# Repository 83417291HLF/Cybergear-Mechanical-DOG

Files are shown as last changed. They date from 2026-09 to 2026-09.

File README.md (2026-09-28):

# Cybergear Mechanical DOG · 8 自由度并联四足机器人

面向 **2026 ROBOCON 竞赛备赛**的四足机器人项目，采用 **RoboMaster A 板、8 个小米 CyberGear 电机和双 CAN 总线**。每条腿由两个电机驱动，软件基于 STM32 HAL，通过 SBUS 遥控生成足端轨迹，并结合板载 IMU 做俯仰、横滚高度补偿。

本文以当前源码和 Keil 工程配置为准。参赛用途由项目作者提供，不表示已经完成赛事规则符合性验证或性能验收。

[代码逐层拆解与问题清单](docs/CODE_WALKTHROUGH.md) · [编译与上机检查](docs/BUILD_AND_BRINGUP.md) · [English](README.en.md)

## 当前实现

| 功能 | 当前代码状态 |
| --- | --- |
| 8 电机控制 | CAN1：ID 1–4；CAN2：ID 5–8，运控模式 |
| 遥控输入 | USART1 + DMA + IDLE，解析 10 个 SBUS 通道 |
| 行走 | 前后步幅、左右差动转向、原地踏步 |
| 步态 | 对角腿相差半周期，摆动相使用摆线轨迹，支撑相匀速回摆 |
| 姿态补偿 | MPU6500 + IST8310 → 四元数姿态解算 → 腿高补偿 |
| 关节控制 | 几何 IK、位置限幅、关节弹簧阻尼力矩补偿、电机内部 PD |
| VMC / 跳跃 | 存在实验文件，但未接入当前 Keil 编译目标和主循环 |
| 调度 | 裸机轮询，目标周期 10 ms；当前主程序未启动 FreeRTOS |

**当前版本属于开发代码快照。** 静态检查发现 SBUS DMA 缓冲区长度不一致、失联分支可继续读取旧指令、反馈角度与控制角度单位不一致等问题，详见[代码拆解](docs/CODE_WALKTHROUGH.md)。归档不代表固件已经通过编译或实机验证。

## 软件结构

```text
software/sizujixgou1123/
├── Core/                   STM32 初始化、主循环、中断入口
├── Drivers/                STM32F4 HAL、CMSIS 与芯片头文件
├── MDK-ARM/
│   ├── sizujixgou1123.uvprojx  Keil 工程入口
│   ├── CyberGear/          电机协议、反馈解析、CAN BSP
│   ├── SBUS/               遥控接收与解析
│   ├── leg/                当前步态、IK；另含实验性 VMC 等文件
│   ├── MPU6500/            IMU 读取、四元数姿态解算
│   ├── IST8310/            磁力计驱动、标量卡尔曼滤波
│   └── RTE/               配置及未接入的跳跃实验代码
└── sizujixgou1123.ioc      STM32CubeMX 配置
三维模型/                   机械设计资料
CyberGear微电机/            电机说明书、模型、固件等参考资料
docs/                       代码分析、编译与上机说明
```

```mermaid
flowchart TD
    RC[SBUS 遥控器] --> UART[USART1 DMA / IDLE 回调]
    UART --> Remote[remoter 通道状态]
    Remote --> Control[update_control_from_remote]
    IMU[MPU6500 + IST8310] --> Attitude[mpu_get_data / IMUupdate1]
    Attitude --> Gait[update_quadruped_gait]
    Control --> Gait
    Gait --> IK[leg_set_position_idx：IK + 关节补偿]
    IK --> Motor[motor_controlmode]
    Motor --> CAN[CAN1 / CAN2]
    CAN --> Eight[8 个 CyberGear 电机]
    Eight --> Feedback[CAN 接收中断：角度 / 速度 / 力矩 / 温度]
    Feedback --> IK
```

## 硬件与电机映射

| 项目 | 当前源码配置 |
| --- | --- |
| 主控 | RoboMaster A 板，STM32F427IIHx |
| 时钟 | 外部时钟 12 MHz，SYSCLK 168 MHz，APB1 42 MHz |
| CAN1 | PD0 RX / PD1 TX；1 Mbit/s |
| CAN2 | PB12 RX / PB13 TX；1 Mbit/s |
| 遥控串口 | USART1，PB7 RX / PB6 TX，100000 baud，8 数据位 + 偶校验 + 2 停止位（HAL 配置为 9B 含校验） |
| 调试串口 | UART7，PE7 RX / PE8 TX，115200 baud，8N1 |
| 惯性传感器 | SPI5 连接 MPU6500，驱动同时读取 IST8310 |

CAN 位率由 `42 MHz / [3 × (1 + 9 + 4)] = 1 MHz` 推导。实际接线还应核对 A 板接口标识及收发器连接。

| 腿编号 | 源码约定位置 | 电机 ID | 总线 | 步态相位 |
| --- | --- | --- | --- | --- |
| 0 | 左前 LF | 1、2 | CAN1 | 0 |
| 1 | 左后 LH | 3、4 | CAN1 | 0.5 |
| 2 | 右后 RH | 5、6 | CAN2 | 0 |
| 3 | 右前 RF | 7、8 | CAN2 | 0.5 |

位置由姿态补偿分组与 VMC 头文件交叉核对，装配后仍须逐电机确认。右侧腿发送的位置和力矩取反；实际代码中 **0/2 同相，1/3 同相**，部分旧注释与此不一致。

## 遥控映射

以下 CH 编号从 1 开始，`ch[]` 下标从 0 开始。解析以原始值 992 为中心。

| 通道 | 数组下标 | 功能 |
| --- | --- | --- |
| CH1 | `ch[0]` | 转向步幅；死区 40，最终限幅 ±60 mm |
| CH3 | `ch[2]` | 前后步幅；死区 40，取反映射，限幅 ±90 mm |
| CH5 | `ch[4]` | 非零时允许前后/转向指令，零时清零两者 |
| CH6 | `ch[5]` | 大于 500 时原地踏步；当前独立于 CH5 |
| CH7 | `ch[6]` | 大于 500：抬腿 130 mm、周期 0.3 s；否则 60 mm、0.2 s |
| CH8 | `ch[7]` | 大于 500：190 mm；小于 −500：270 mm；中间：213.2 mm 基准高度 |

CH5 当前不是整机急停，关闭后仍发送站立命令，CH6 可以继续触发踏步。遥控器开关的实际输出须先通过通道监测确认。`side_s` 字段未进入当前轨迹计算，不能据此宣称支持横移。

## 编译入口与关键参数

打开 [Keil 工程](software/sizujixgou1123/MDK-ARM/sizujixgou1123.uvprojx)。工程记录的工具链为 ARMCC 5.05 update 1，器件包为 `Keil.STM32F4xx_DFP.2.17.0`。完整步骤见[编译与上机检查](docs/BUILD_AND_BRINGUP.md)。

| 参数 | 源码当前值 | 位置 |
| --- | --- | --- |
| 几何尺寸 | L1 = 100 mm，L2 = 200 mm，足端延长 = 45 mm | `leg/leg.h` |
| 角度偏置 | π/2 | `leg/leg.h` |
| 默认高度 / 抬腿高度 / 周期 | 213.2 mm / 60 mm / 0.2 s | `leg/leg.c` |
| 姿态补偿增益 | pitch、roll 均为 2 mm/° | `leg/leg.c` |
| 补偿限幅 / 变化率 | 每腿合成补偿 ±100 mm / 每轴 20 mm/s | `leg/leg.c` |
| 关节目标限幅 | 镜像前 −1.2～1.4 rad | `leg/leg.c` |
| 运控 PD | Kp = 13，Kd = 0.9 | `leg/leg.c` |

这些数值是源码参数，不是整机性能指标或本次测试的推荐参数。

## 后续开发重点

1. 修复接收越界、失联处理与反馈单位，建立明确的停机状态。
2. 统一左右腿坐标、关节方向和零位标定，修正 IK 可达域处理。
3. 测量控制周期，减少 CAN 重复发送与阻塞延时。
4. 修正姿态滤波状态共享，补充传感器有效性判断。
5. 在单腿测试通过后，验证完整并联机构的 FK / Jacobian 和 VMC。

## 仓库说明

源码、CubeMX/Keil 配置与机械资料用于协作维护。生成目标文件、历史构建产物、IDE 用户状态、重复的 `software.zip` 和第三方上位机运行包不纳入版本控制，本地文件保留。源码混有不同中文编码，本次文档整理不批量转码控制代码。

当前未为作者自有代码新增开源许可证；第三方 HAL、CMSIS 及电机驱动保留原有许可文件与作者声明。公开仓库不自动授予任意再分发许可。

远端原有的历史归档 `sizujixgou1123 (3).zip` 保留；阅读和后续开发以展开后的 `software/` 为准。

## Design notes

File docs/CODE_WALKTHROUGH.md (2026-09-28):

# 从代码拆解 Cybergear Mechanical DOG

分析对象为 `software/sizujixgou1123`。相对路径以下均以该目录为起点。分析依据为源码、函数调用和 `.uvprojx` 源文件清单，不以旧编译产物推断当前功能。

## 1. 入口与执行时序

[`Core/Src/main.c`](../software/sizujixgou1123/Core/Src/main.c) 的执行顺序：

```text
HAL_Init → SystemClock_Config
→ GPIO / DMA / CAN1 / CAN2 / USART1 / UART7 / TIM6 / TIM7 / SPI5 初始化
→ can_bsp_init
→ USART1 ReceiveToIdle DMA → 启动 TIM6 中断
→ mpu_device_init → quadruped_init
→ while (1)
    每当 HAL_GetTick 差值 ≥ 10 ms：
        mpu_get_data
        update_control_from_remote
        update_quadruped_gait(0.01)
    每 500 ms 翻转 LED
```

当前调度是裸机轮询。TIM2 回调负责 `HAL_IncTick()`；TIM6 虽然启动，但 `HAL_TIM_PeriodElapsedCallback()` 未实现 TIM6 的控制任务。旧输出目录中的 `freertos.o`、`tasks.o` 不代表当前主程序在运行 RTOS。

这里的 100 Hz 是目标频率：`last_tick = now`，传入的 `dt` 固定为 0.01。发送电机命令的阻塞延时和传感器读取可能造成超期，超期后没有追赶执行或真实时间步长修正。

## 2. 遥控输入层

[`MDK-ARM/SBUS/sbus.c`](../software/sizujixgou1123/MDK-ARM/SBUS/sbus.c) 在 USART1 的 IDLE/DMA 回调中解析 SBUS 数据：检查首字节 `0x0F`、尾字节 `0x00`，从 11-bit 打包数据提取 10 通道，统一减去 992。

[`update_control_from_remote()`](../software/sizujixgou1123/MDK-ARM/leg/leg.c) 将通道转换为步态参数：前后步幅 `S`、转向步幅 `yaw_s`、踏步标志、抬腿高度 `H`、周期 `T_cycle` 和基准腿高。步幅采用 `0.8 × 旧值 + 0.2 × 目标值` 平滑；它们是毫米尺度的轨迹幅度，不是 m/s 的速度命令。

CH5 仅控制前后/转向，CH6 独立触发原地踏步。`side_s` 虽然声明在 `GaitConfig`，当前没有进入轨迹生成。

## 3. 足端轨迹和机身姿态补偿

主要逻辑集中在 [`MDK-ARM/leg/leg.c`](../software/sizujixgou1123/MDK-ARM/leg/leg.c)。

每条腿的步幅：左侧 `S + yaw_s`，右侧 `S - yaw_s`。相位表达式为：

```c
phase = timer / T_cycle + ((i == 1 || i == 3) ? 0.5f : 0.0f);
```

因此是 0/2 同相、1/3 同相，配合 LF/LH/RH/RF 腿序形成对角配对。旧注释所写的“0、3 同相”与表达式不同。

摆动相占半周期，归一化时间为 `s`，`sigma = 2πs`：

```text
x = -步幅/2 + 步幅 × (sigma - sin(sigma)) / (2π)
y = y_base - H × (1 - cos(sigma)) / 2
```

支撑相令 x 从正半步幅线性回到负半步幅，y 保持基准高度并叠加补偿。停止行走时 timer 清零，各腿 x = 0，但仍更新姿态补偿和电机位置。

姿态链路为 `mpu_get_data → IMUupdate1 → imu.pit0/rol0 → 腿高补偿`。每轴按 2 mm/° 放大，经过系数 0.4 的低通及 20 mm/s 变化率限制，再按前后、左右腿加减；每腿合成补偿限制为 ±100 mm。行走时只在支撑相补偿，静止时四腿均补偿。

`y_base += (target_y_base - y_base) * 1.0f` 实际一步到达目标，不具备注释暗示的渐变效果。IMU 反馈单位是度，几何 IK 和电机目标使用弧度，二者不可混用。

## 4. 单腿 IK 与关节补偿

[`leg_set_position_idx()`](../software/sizujixgou1123/MDK-ARM/leg/leg.c) 使用 `L1 = 100`、`L2_EFF = 200 + 45 = 245` mm 和 π/2 偏置。

先做左右镜像，再以足端距离 L、方向角 psi 和余弦定理求 phi：

```text
L² = cx² + cy²
psi = asin(-cx/L)
phi = acos((L² + L1² - L2_EFF²)/(2 L1 L))
pos1 = -(phi - psi) + π/2
pos2 = -(phi + psi) + π/2
```

这描述源码采用的几何模型；完整并联连杆闭环、装配分支和实际零位仍须与机械图纸及单腿测量对照。

附加力矩公式是 `tau = stiffness × (目标角 - 反馈角) - 0.1 × 反馈速度`。刚度为 `2 × clamp(213.2/y, 0.8, 1.5)`，力矩限幅 ±12，位置在镜像前限幅 −1.2～1.4 rad，最终传入 `motor_controlmode(..., 13, 0.9)`。右侧位置和力矩发送前取负。

因此当前是**位置轨迹 + 关节空间弹簧阻尼补偿 + 电机内部 PD**。足端力通过 `JᵀF` 分配的实验性 VMC 没有进入这条运行链路。

## 5. CAN 与电机协议层

[`CyberGear/bsp_CAN.c`](../software/sizujixgou1123/MDK-ARM/CyberGear/bsp_CAN.c) 启动两条总线，用过滤器组 0、14 接收 FIFO0 中断，当前掩码放行全部 ID。

[`CyberGear/cybergear.c`](../software/sizujixgou1123/MDK-ARM/CyberGear/cybergear.c) 封装使能、停止、设零位、参数写入、运控和反馈解码。运控帧将位置、速度、Kp、Kd 各编码为 16 位并填入 8 字节载荷，力矩编码进入扩展 ID。主机 ID 定义为 `0xFD`。

`can_txd(hcan)` 是头文件宏，展开为 `HAL_CAN_AddTxMessage(hcan, &txMsg, tx_data, &send_mail_box)`，所以函数内的局部 `tx_data` 会实际传入 HAL，并非丢失载荷。当前真正的问题是 `motor_controlmode()` 在等待邮箱前后调用该宏两次，存在重复发送和首发失败未处理的问题。

接收回调根据总线及电机 ID 分发给 `mi_motor_can1/2[0..3]`，更新角度、速度、力矩、温度和错误位。数组实际声明容量为 5，每条总线只初始化 4 个元素。

## 6. 当前目标之外的文件

`.uvprojx` 中的主要业务源文件是 `leg.c`、`cybergear.c`、`bsp_CAN.c`、`sbus.c`、`mpu6500.c`、`process.c`、`mahony.c`、`ist8310.c`、`kalman.c`。加入工程不意味着所有函数均被调用：姿态实际入口是 `IMUupdate1()`。

| 文件 | 检查结果 |
| --- | --- |
| `leg/quadruped_vmc.c/.h` | 未加入当前编译目标；尝试足端弹簧力与 Jacobian 转置控制 |
| `leg/gait_planner.c` | 未加入目标；包含不存在的 `leg0_config.h`，依赖 `leg0` |
| `leg/robot_config.c` | 当前为空文件，不能视作集中参数管理已经实现 |
| `RTE/jump.c/.h` | 未加入当前编译目标 |
| `dm_IMU.c`、`dm_imu.h`、`SBUS/dm_imu.*`、`imu.c` | 当前工程未选用的其他 IMU 相关文件 |

VMC 实验代码的头文件写 12 kg，而 `.c` 内定义 10 kg；足端误差直接使用毫米，刚度注释为 N/m，尚未统一单位。其 Jacobian 表达式也需要按真实并联机构闭环重新推导，不能直接视作验证过的整机力控。

## 7. 已确认的问题与待验证项

以下为静态审查结果，本次归档未修改控制源码。优先级表示修复顺序，不表示实机已复现。

| 优先级 | 位置与证据 | 影响及处理方向 |
| --- | --- | --- |
| P0 | `sbus.h` 定义 `BUFF_SIZE=25`、`sbus.c` 分配 25 字节，但 main 与回调都启动 `BUFF_SIZE*2` 的 DMA | DMA 可写到缓冲区之外；统一容量与长度，在完整帧校验后解析 |
| P0 | `update_control_from_remote()` 的离线分支只清零步幅，没有 return；后续读取旧通道 | 旧通道可以重新恢复运动；离线必须终止控制输入处理并清理踏步状态 |
| P0 | `sbus_frame_parse()` 仅用 `buf[23] == 0x0C` 判离线，无接收超时 | 断线不再收帧时可一直保持在线；应按位检查故障标志并加入有效帧时间戳 |
| P1 | `Motor_Data_Handler()` 用 `MIN_P=-720/MAX_P=720` 解码 Angle，IK 目标直接以 rad 与它相减 | 反馈与控制数值尺度不一致；统一单位后重新验证补偿，不可只调增益 |
| P1 | `motor_controlmode()` 连续两处 `can_txd`，返回值未检查，末尾 `HAL_Delay(1)` | 命令重复、丢帧不可见、周期预算被占用；改为单次受控发送并统计失败 |
| P1 | SBUS 回调在解析前重启 DMA，且允许 `Size < 25` 时进入解析 | 读写竞争及残留数据可能被当作完整帧；增加帧长验证、快照/双缓冲和重同步 |
| P1 | `check_and_recover_motors()` 遍历 CAN1 的 0..7，数组容量仅 5，且遗漏 CAN2 | 潜在越界；当前主循环未调用，接入前必须修复为两总线各 4 个，不能自动无条件恢复 |
| P1 | 右侧发送目标取反，但误差计算直接使用未转换的右侧反馈 | 即便修正角度单位仍可能符号错误；定义统一关节坐标，反馈与目标采用同一转换 |
| P1 | IK 限制 L 后仍在余弦公式中使用原始 L_sq | 越界足端目标没有被一致投影到可达域；同时调整坐标/距离及平方项 |
| P1 | `KalmanFilter()` 用单份 static 状态，`IMUupdate1()` 对 pitch/roll/yaw 连续调用 | 三轴滤波互相污染；每轴使用独立状态 |
| P1 | `IMUupdate1()` 对加速度、磁场和四元数模长直接相除 | 零/无效测量可传播 NaN；增加有效性门限，首帧时间初始化及异常恢复 |
| P1 | `quadruped_init()` 上电即使能、设零位、发零角命令 | 任意上电姿态可能改变机械参考；拆分标定与运行状态 |
| P2 | 高度调整系数是 1，固定 dt，CAN 反馈无帧类型/DLC/时效完整检查 | 高度跃变、时序误差和无效反馈风险；增加速率限制、实际周期统计及反馈验证 |

推荐先修复内存与失联问题，再统一单位和坐标，随后验证时序及 IMU，最后开展 VMC。每一步都应保留单腿/整机测量记录。

## 8. 验证边界

本次属于代码阅读、工程清单核对与文档整理；没有用历史构建日志代替当前编译，没有宣称机器人已达到某个速度、负载、跳跃高度或竞赛成绩。编译与硬件测试步骤见[上机说明](BUILD_AND_BRINGUP.md)。

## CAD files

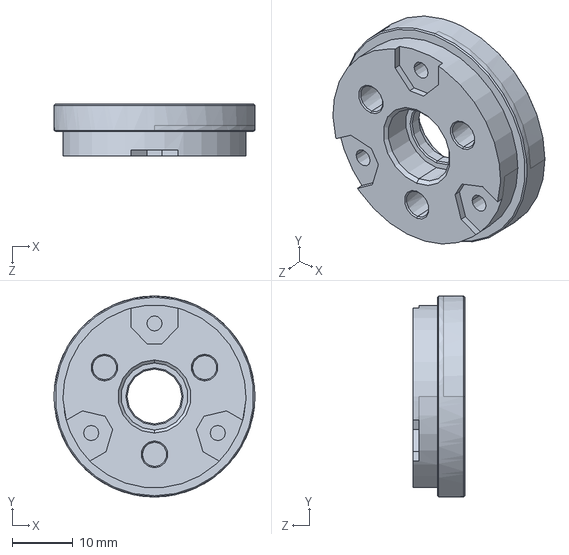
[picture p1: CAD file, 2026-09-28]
CyberGear微电机/电机三维图纸/1_1_02_EB671-500_1_1_1_1_1.SLDPRT
33.0 x 33.0 x 8.50 mm

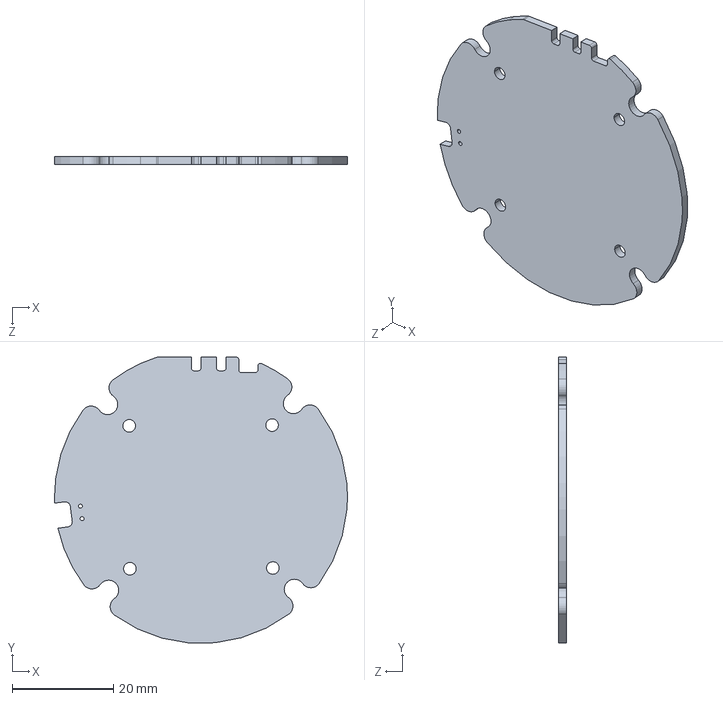
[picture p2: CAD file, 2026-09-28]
CyberGear微电机/电机三维图纸/0411-2_4_1_3_1.SLDPRT
58.0 x 56.6 x 1.61 mm

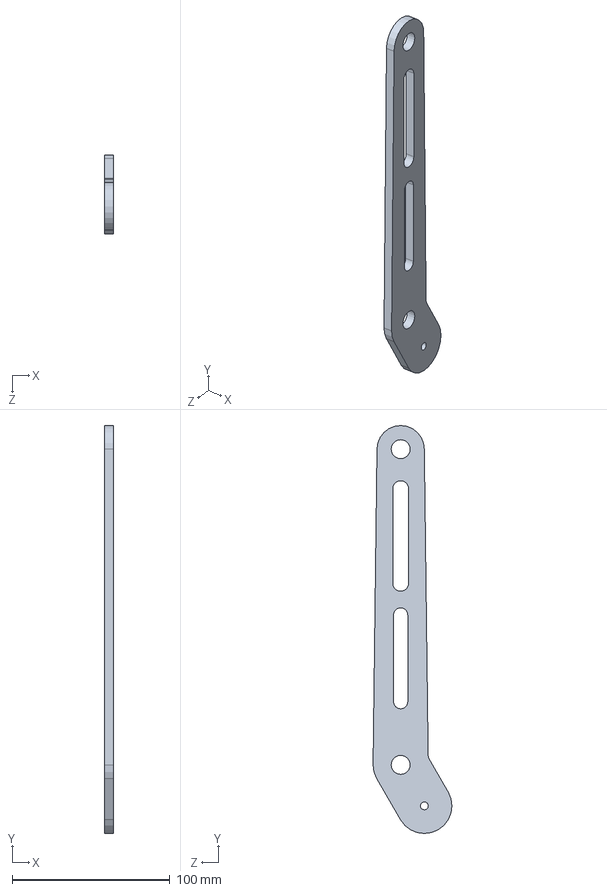
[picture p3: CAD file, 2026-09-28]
三维模型/ZZZ-并联四足/ZZZ-小腿2.SLDPRT
6.00 x 258.5 x 50.0 mm

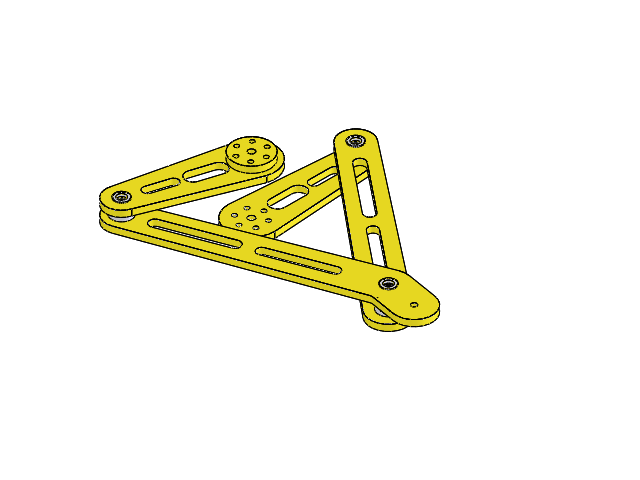
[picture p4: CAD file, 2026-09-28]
三维模型/ZZZ-并联四足/ZZZ-并联腿装配右.SLDASM
ZZZ-大腿1 x 2
ZZZ-大腿2 x 2
ZZZ-挡边轴承8-12-2.5 x 12
ZZZ-推力球轴承F8-19M x 4
ZZZ-小腿1
ZZZ-小腿2

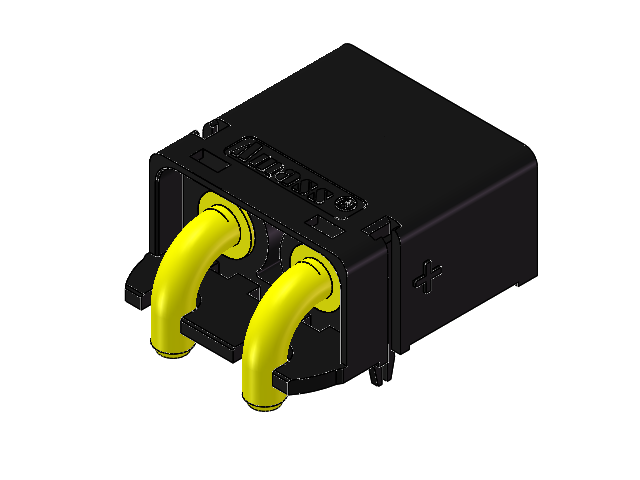
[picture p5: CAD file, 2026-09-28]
三维模型/ZZZ-并联四足/XT60_____ASM.SLDASM
XT60____-8________-2-SOLID1
XT60____-8____-21157-2-SOLID1
XT60____-8______-UL-21156-1-SOL
XT60____-8____-21157-1-SOLID1
XT60____-8________-1-SOLID1

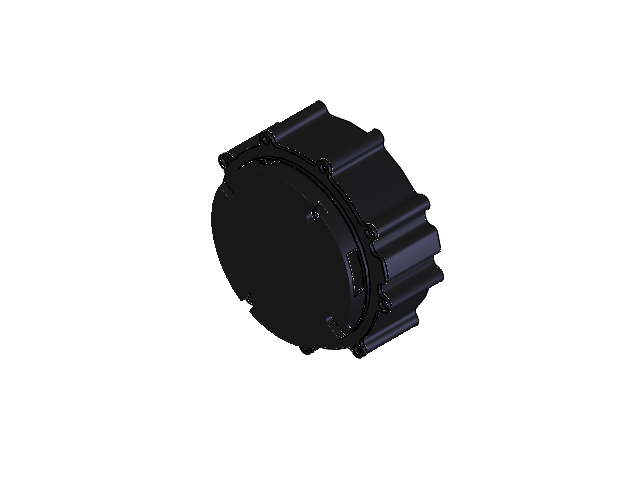
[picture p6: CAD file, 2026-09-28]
CyberGear微电机/电机三维图纸/3_1_02_067_0003_ASM_1_ASM_1_ASM_ASM.SLDASM
1_1_06_EB673-504_1_1_1_1_1
1_1_02_EB671-500_1_1_1_1_1
1_1_31_QT-642_1_1_1_1_1
1_1_06_EB673-502_1_1_1_1_1

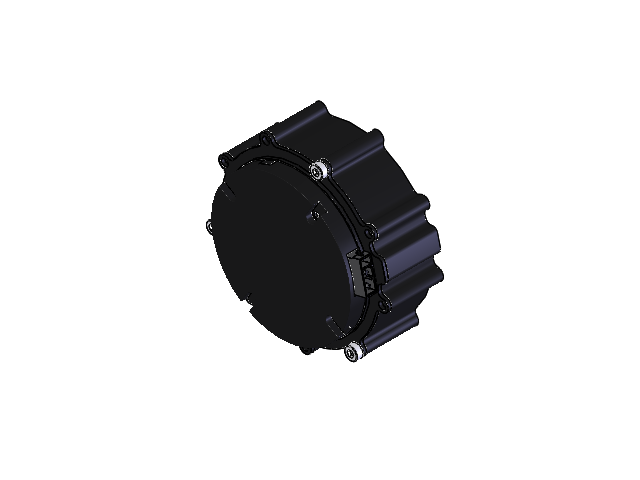
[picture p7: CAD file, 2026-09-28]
CyberGear微电机/电机三维图纸/ASM0002_ASM_1_ASM_1_ASM.SLDASM
1_1_06_EB673-504_1_1_1_1_1
1_1_02_EB671-500_1_1_1_1_1
1_1_31_QT-642_1_1_1_1_1
1_1_06_EB673-502_1_1_1_1_1
DUANZI_1_3_1_1_1_1_1_1
LUODING_1_1 x 3

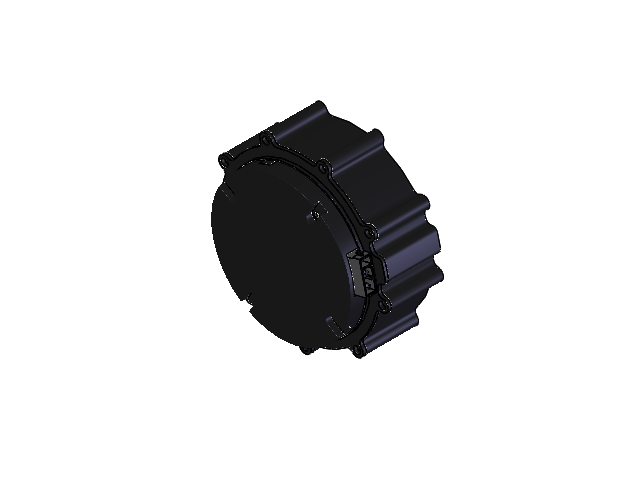
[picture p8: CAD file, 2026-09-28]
CyberGear微电机/电机三维图纸/0714_ASM_1_ASM_1_ASM_1_ASM.SLDASM
1_1_06_EB673-504_1_1_1_1_1
1_1_02_EB671-500_1_1_1_1_1
1_1_31_QT-642_1_1_1_1_1
1_1_06_EB673-502_1_1_1_1_1
DUANZI_1_3_1_1_1_1_1_1

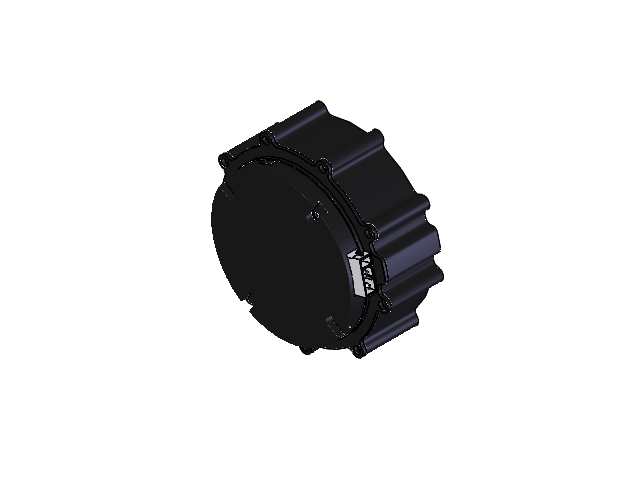
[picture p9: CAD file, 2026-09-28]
CyberGear微电机/电机三维图纸/3_1_02_067_0003_ASM_ASM_1_ASM_1_ASM.SLDASM
1_1_06_EB673-504_1_1_1_1_1
1_1_02_EB671-500_1_1_1_1_1
1_1_31_QT-642_1_1_1_1_1
1_1_06_EB673-502_1_1_1_1_1
DUANZI_1_3_1_1_1_1_1_1

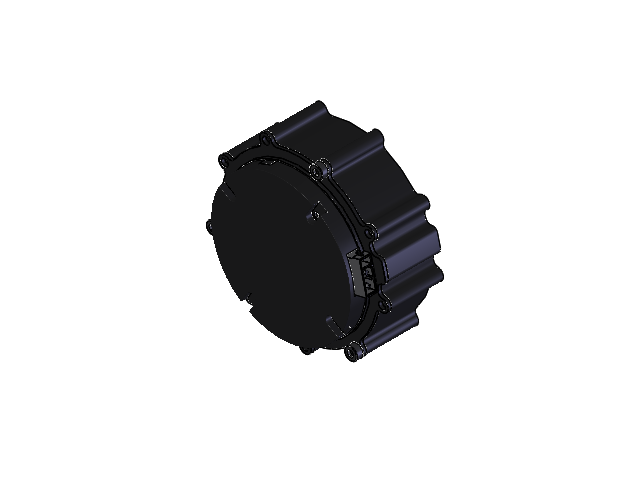
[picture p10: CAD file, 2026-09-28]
CyberGear微电机/电机三维图纸/ASM0002_ASM_1_ASM.SLDASM
1_1_06_EB673-504_1_1_1_1_1
1_1_02_EB671-500_1_1_1_1_1
1_1_31_QT-642_1_1_1_1_1
1_1_06_EB673-502_1_1_1_1_1
DUANZI_1_3_1_1_1_1_1_1
LUODING_1_1 x 3

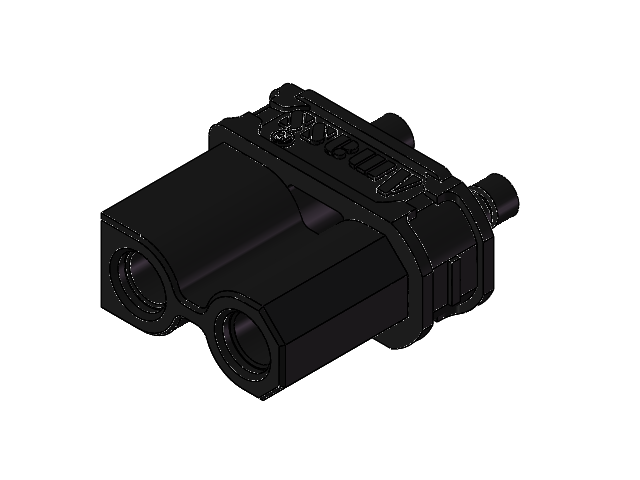
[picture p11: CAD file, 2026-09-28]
三维模型/ZZZ-并联四足/XT30UPB-F_ASM.SLDASM
MR30PB-F__ x 2
XT30UPB-F_SJ

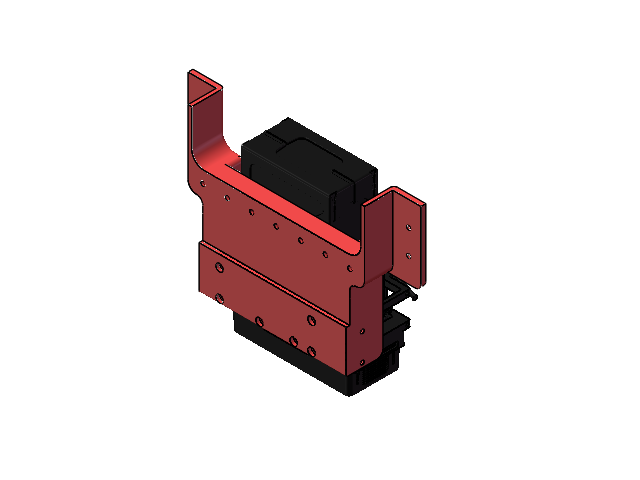
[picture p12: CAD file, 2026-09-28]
三维模型/ZZZ-并联四足/装配体8445.SLDASM
ZZZ-电池连接件
TB48电池架_外购件_01

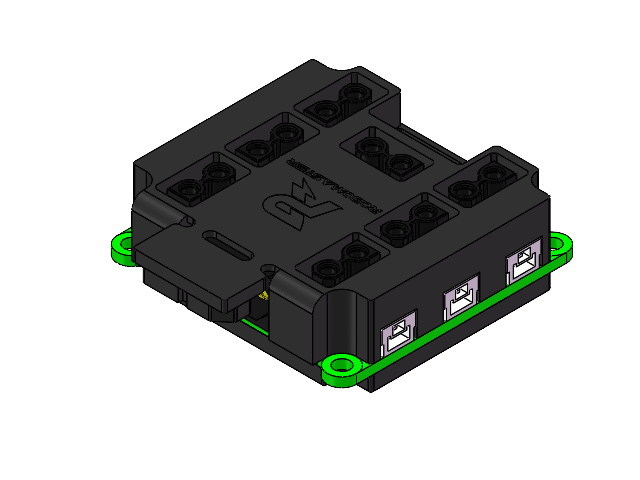
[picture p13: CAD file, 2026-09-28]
三维模型/ZZZ-并联四足/RM_ESC_Center_Board21.SLDASM
CENTER_DISTRIBUTION_BOARD
MR30PB-F__ x 14
XT30UPB-F_SJ x 7
XT60____-8________-2-SOLID1
XT60____-8____-21157-2-SOLID1
XT60____-8______-UL-21156-1-SOL
XT60____-8____-21157-1-SOLID1
XT60____-8________-1-SOLID1
SM02B-GHS-TB x 6
BM04B-GHS-TBT
BM02B-GHS-TBT
SHELL_UP
SHELL_DOWN

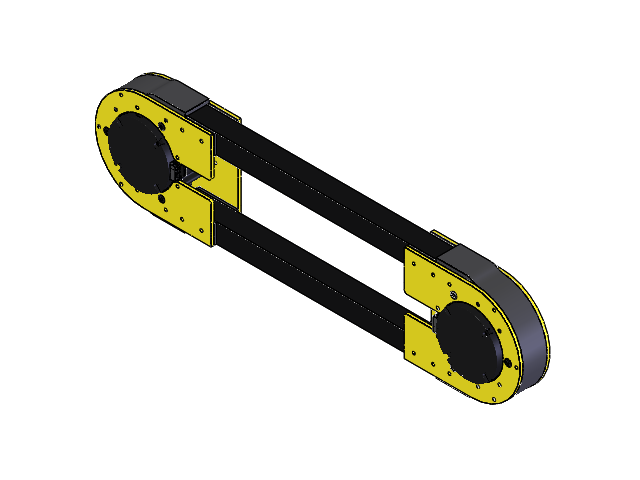
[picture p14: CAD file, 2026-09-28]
三维模型/ZZZ-并联四足/ZZZ-并联四足单装配.SLDASM
ZZZ-电机内板 x 2
1_1_06_EB673-504_1_1_1_1_1 x 2
1_1_02_EB671-500_1_1_1_1_1 x 2
1_1_31_QT-642_1_1_1_1_1 x 2
1_1_06_EB673-502_1_1_1_1_1 x 2
DUANZI_1_3_1_1_1_1_1_1 x 2
LUODING_1_1 x 6
ZZZ-电机外板 x 2
ZZZ-铝方管20-20-340mm x 2
ZZZ-腿垫块1 x 2

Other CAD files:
CyberGear微电机/电机三维图纸/0518_ASM_2_ASM_1_ASM_1_ASM_1_AS_ASM.SLDASM
三维模型/ZZZ-并联四足/ZZZ-并联总装.SLDASM
三维模型/ZZZ-并联四足/XT30UPB-F_3D_DRAWING_ASM.SLDASM
三维模型/ZZZ-并联四足/ZZZ-并联腿装配.SLDASM
CyberGear微电机/电机三维图纸/12345_ASM_1_ASM_2_ASM_1_ASM_1_A_ASM.SLDASM
CyberGear微电机/电机三维图纸/1_1_06_EB673-502_1_1_1_1_1.SLDPRT
CyberGear微电机/电机三维图纸/1_1_06_EB673-504_1_1_1_1_1.SLDPRT
CyberGear微电机/电机三维图纸/1_1_31_QT-642_1_1_1_1_1.SLDPRT
CyberGear微电机/电机三维图纸/1_2_04_670601_1_1_1_1_1.SLDPRT
CyberGear微电机/电机三维图纸/1_2_04_694000_1_1_1_1_1.SLDPRT
CyberGear微电机/电机三维图纸/1_2_06_000213_1_1_1_1_1.SLDPRT
CyberGear微电机/电机三维图纸/CyberGearmotor(2).SLDASM
CyberGear微电机/电机三维图纸/CyberGearmotor.SLDASM
CyberGear微电机/电机三维图纸/CyberGearmotor.stp
CyberGear微电机/电机三维图纸/DUANZI_1_3_1_1_1_1_1_1.SLDPRT
CyberGear微电机/电机三维图纸/LUODING_1_1.SLDPRT
三维模型/ZZZ-并联四足/BM02B-GHS-TBT.SLDPRT
三维模型/ZZZ-并联四足/BM04B-GHS-TBT.SLDPRT
三维模型/ZZZ-并联四足/CENTER_DISTRIBUTION_BOARD.SLDPRT
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

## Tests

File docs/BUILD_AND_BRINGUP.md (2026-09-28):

# 编译与上机检查

## 工程入口

打开 [sizujixgou1123.uvprojx](../software/sizujixgou1123/MDK-ARM/sizujixgou1123.uvprojx)，目标 `sizujixgou1123`，芯片 `STM32F427IIHx`。

工程 XML 记录 ARMCC `V5.05 update 1 (build 106)` 与器件包 `Keil.STM32F4xx_DFP.2.17.0`。先恢复匹配环境，再考虑编译器迁移；本次未验证 ARMClang 兼容性。

1. 在 Keil 中确认编译器、器件包和包含目录可用。
2. 执行 Rebuild，处理错误并检查隐式函数声明等警告。
3. 确认固件来自当前源码；旧 `.hex`、`.axf` 和日志不能证明当前版本可构建。
4. 核对调试器、SWD 和下载配置后再下载。

工程包含 HAL/CMSIS 源码。当前没有经过验证的 CMake、GCC 或 PlatformIO 构建流程。

## CubeMX 与源码边界

`.ioc` 保存外设配置，自定义逻辑位于 `Core/Src/main.c` 和 `MDK-ARM`。重新生成代码前先提交当前版本，生成后重点检查主循环、DMA 接收入口、CAN/串口引脚、TIM2 HAL 时基和自定义源文件清单。

运行时配置采用 12 MHz HSE、168 MHz 系统时钟。Keil XML 的 CPU 描述含 `CLOCK(25000000)`，不能替代 RCC 配置。

## 修复后的上机验证顺序

先阅读[代码问题清单](CODE_WALKTHROUGH.md)。当前快照有明确缺陷，以下是修复后的验证步骤。

1. **遥控输入**：确认 RX 容量、DMA 长度、完整帧判断一致；逐通道核对中心值、方向和开关输出。关闭发射机和拔掉接收机信号均应进入确定的停机状态。
2. **单电机反馈**：检查 CAN1 ID 1–4、CAN2 ID 5–8；确认单位、方向、温度与反馈时效。抓取 CAN 帧确认没有重复发送或静默丢帧。
3. **零位**：`quadruped_init()` 会发送使能、设零位和位置控制命令。应将标定从自动上电流程中分离，按实际机构建立零位姿态。
4. **单腿悬空**：确认电机方向与机械限位，以小位移验证 IK，记录足端实际位置并对照尺寸与坐标定义。
5. **四腿支撑**：依次验证静止站立、高度切换、姿态补偿、踏步、低步幅前后和转向。人工轻微倾斜验证补偿方向。
6. **时序与故障**：记录循环耗时、发送失败数、最长反馈间隔；验证电机掉线、CAN 异常和 IMU 无效数据的处理。

## 本次整理的验证范围

本次核对源码、Keil 编译文件清单、参数与调用关系，并检查工程引用文件和 Markdown 相对链接。未执行 MCU 编译、烧录、CAN 实测或整机运动测试。修复建议单独记录，控制源码保留原样。

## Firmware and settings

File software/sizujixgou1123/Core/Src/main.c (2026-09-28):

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
/* Includes ------------------------------------------------------------------*/
#include "main.h"
#include "can.h"
#include "dma.h"
#include "spi.h"
#include "tim.h"
#include "usart.h"
#include "gpio.h"

/* USER CODE BEGIN Includes */
#include "cybergear.h"
#include "bsp_CAN.h"
#include "leg.h"
#include "stdio.h"
#include "sbus.h"
#include "mpu6500.h"

/* USER CODE END Includes */


/* USER CODE BEGIN PV */
char buf[300];
#define PI 3.1415926
const float dt = 0.01f; 
/* USER CODE END PV */

void SystemClock_Config(void);
/* USER CODE BEGIN PFP */
// uint32_t ssy;
/* USER CODE END PFP */

/**
  * @brief  The application entry point.
  * @retval int
  */
int main(void)
{

  /* MCU Configuration--------------------------------------------------------*/

  /* Reset of all peripherals, Initializes the Flash interface and the Systick. */
  HAL_Init();

  /* Configure the system clock */
  SystemClock_Config();

  /* Initialize all configured peripherals */
  MX_GPIO_Init();
  MX_DMA_Init();
  MX_CAN1_Init();
  MX_CAN2_Init();
  MX_USART1_UART_Init();
  MX_UART7_Init();
  MX_TIM6_Init();
  MX_TIM7_Init();
  MX_SPI5_Init();
  /* USER CODE BEGIN 2 */
  can_bsp_init();
  //	HAL_UARTEx_ReceiveToIdle_DMA(&huart7, rx_buff, BUFF_SIZE*2);
	HAL_UARTEx_ReceiveToIdle_DMA(&huart1, rx_buff, BUFF_SIZE*2);
 	HAL_TIM_Base_Start_IT(&htim6);
	mpu_device_init();
  quadruped_init(); 
  static uint32_t last_led_tick = 0;
static GPIO_PinState led_state = GPIO_PIN_RESET;  // 初始状态（根据硬件决定亮灭）

// 初始设置 LED 为指定状态
HAL_GPIO_WritePin(GPIOG, LED1_Pin, led_state);

  uint32_t last_tick = HAL_GetTick();
  const float dt = 0.01f; 
  /* USER CODE END 2 */

  /* Infinite loop */
  /* USER CODE BEGIN WHILE */
  while (1)
  {
    /* USER CODE END WHILE */

    /* USER CODE BEGIN 3 */
		  uint32_t now = HAL_GetTick();  // 获取当前系统时间（毫秒）

    // 原 10ms 任务
    if (now - last_tick >= 10) {
        last_tick = now;  // 注意：这里应使用更新后的 now，而不是再次调用 HAL_GetTick()

        // 步骤1：读取IMU数据
         mpu_get_data();

        // 步骤2：读取遥控器数据
        update_control_from_remote(&remoter);

        // 步骤3：更新步态
        update_quadruped_gait(dt);
    }
	

    // 新增：LED 非阻塞闪烁（周期 1000ms，即亮 500ms + 灭 500ms）
    if (now - last_led_tick >= 500) {
        last_led_tick = now;
        led_state = (led_state == GPIO_PIN_RESET) ? GPIO_PIN_SET : GPIO_PIN_RESET;
        HAL_GPIO_WritePin(GPIOG, LED1_Pin, led_state);
  }
}
  /* USER CODE END 3 */
}

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
/**
  * @brief  Period elapsed callback in non blocking mode
  * @note   This function is called  when TIM2 interrupt took place, inside
  * HAL_TIM_IRQHandler(). It makes a direct call to HAL_IncTick() to increment
  * a global variable "uwTick" used as application time base.
  * @param  htim : TIM handle
  * @retval None
  */
void HAL_TIM_PeriodElapsedCallback(TIM_HandleTypeDef *htim)
{
  if (htim->Instance == TIM2)
  {
    HAL_IncTick();
  }
}

/**
  * @brief  This function is executed in case of error occurrence.
  * @retval None
  */
void Error_Handler(void)
{
  /* USER CODE BEGIN Error_Handler_Debug */
  /* User can add his own implementation to report the HAL error return state */
  __disable_irq();
  while (1)
  {
  }
  /* USER CODE END Error_Handler_Debug */
}

#ifdef  USE_FULL_ASSERT
/**
  * @brief  Reports the name of the source file and the source line number
  *         where the assert_param error has occurred.
  * @param  file: pointer to the source file name
  * @param  line: assert_param error line source number
  * @retval None
  */
void assert_failed(uint8_t *file, uint32_t line)
{
  /* USER CODE BEGIN 6 */
  /* User can add his own implementation to report the file name and line number,
     ex: printf("Wrong parameters value: file %s on line %d\r\n", file, line) */
  /* USER CODE END 6 */
}
#endif /* USE_FULL_ASSERT */

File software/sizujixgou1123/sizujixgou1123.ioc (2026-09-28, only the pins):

Mcu.UserName=STM32F427IIHx
PA13.Signal=SYS_JTMS-SWDIO
PA14.Signal=SYS_JTCK-SWCLK
PB12.Signal=CAN2_RX
PB13.Signal=CAN2_TX
PB6.Signal=USART1_TX
PB7.Signal=USART1_RX
PC2.GPIO_Label=S4
PC2.Signal=GPIO_Output
PC3.GPIO_Label=S5
PC3.Signal=GPIO_Output
PC4.GPIO_Label=S6
PC4.Signal=GPIO_Output
PC5.GPIO_Label=S7
PC5.Signal=GPIO_Output
PD0.Signal=CAN1_RX
PD1.Signal=CAN1_TX
PE5.GPIO_Label=S2
PE5.Signal=GPIO_Output
PE6.GPIO_Label=S3
PE6.Signal=GPIO_Output
PE7.Signal=UART7_RX
PE8.Signal=UART7_TX
PF1.GPIO_Label=S1
PF1.Signal=GPIO_Output
PF6.Signal=GPIO_Output
PF7.Signal=SPI5_SCK
PF8.Signal=SPI5_MISO
PF9.Signal=SPI5_MOSI
PG1.GPIO_Label=LED1
PG1.Signal=GPIO_Output
PG2.GPIO_Label=LED2
PG2.Signal=GPIO_Output
PG3.GPIO_Label=LED3
PG3.Signal=GPIO_Output
PG4.GPIO_Label=LED4
PG4.Signal=GPIO_Output
PG5.GPIO_Label=LED5
PG5.Signal=GPIO_Output
PG6.GPIO_Label=LED6
PG6.Signal=GPIO_Output
PG7.GPIO_Label=LED7
PG7.Signal=GPIO_Output
PG8.GPIO_Label=LED8
PG8.Signal=GPIO_Output
PH0/OSC_IN.Signal=RCC_OSC_IN
PH1/OSC_OUT.Signal=RCC_OSC_OUT

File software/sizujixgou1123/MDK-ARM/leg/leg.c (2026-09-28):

#include "leg.h"
#include <stdlib.h>
#include "process.h" 
#include "mpu6500.h"// 里面定义了 imu 结构体
extern imu_t imu;      // 姿态数据
// ================== 全局步态参数初始化 ==================
GaitConfig myGait = {
    .S = 0.0f,
    .side_s = 0.0f,
    .yaw_s = 0.0f,
    .H = 60.0f,
    .T_cycle = 0.2f,
    .y_base = 213.2f,
    .timer = 0.0f,
    .stepping_in_place = 0
};

static float target_y_base = 213.2f;

// ================== 姿态自适应补偿滤波器状态 ==================
static float comp_pitch_lpf = 0.0f;   // 俯仰补偿量平滑值 (mm)
static float comp_roll_lpf  = 0.0f;   // 横滚补偿量平滑值 (mm)
static float last_comp_pitch = 0.0f;  // 用于速率限制
static float last_comp_roll  = 0.0f;
// ================== 工具 ==================
static inline float clamp_f(float v, float min, float max)
{
    return (v < min) ? min : ((v > max) ? max : v);
}

void quadruped_init(void)
{
    HAL_Delay(300);

    // 初始化 CAN1 电机 (ID 1-4)
    for (uint8_t i = 0; i < 4; i++) {
			 
        init_cybergear(&mi_motor_can1[i], i + 1, Motion_mode, &hcan1);  // 运控模式
        HAL_Delay(300);
        start_cybergear(&mi_motor_can1[i]);
			  Set_Cyber_ZeroPos(&mi_motor_can1[i]);  // 可选
        HAL_Delay(100);
        //限速、限流、Kp
        Set_Motor_Parameter(&mi_motor_can1[i], Limit_Spd, 30.0f, 'f');
        Set_Motor_Parameter(&mi_motor_can1[i], Limit_Cur, 12.0f, 'f');
        Set_Motor_Parameter(&mi_motor_can1[i], Loc_Kp, 15.0f, 'f');
        motor_controlmode(&mi_motor_can1[i], 0.0f, 0.0f, 0.0f, 8.0f, 0.5f);
        HAL_Delay(5);
        
    }
    for (uint8_t i = 0; i < 4; i++) {
			 
        init_cybergear(&mi_motor_can2[i], i + 5, Motion_mode, &hcan2);  // 运控模式
        HAL_Delay(300);
        start_cybergear(&mi_motor_can2[i]);
			  Set_Cyber_ZeroPos(&mi_motor_can2[i]);  // 可选
        HAL_Delay(100);
        //限速、限流、Kp
        Set_Motor_Parameter(&mi_motor_can2[i], Limit_Spd, 30.0f, 'f');
        Set_Motor_Parameter(&mi_motor_can2[i], Limit_Cur, 12.0f, 'f');
        Set_Motor_Parameter(&mi_motor_can2[i], Loc_Kp, 15.0f, 'f');
        motor_controlmode(&mi_motor_can2[i], 0.0f, 0.0f, 0.0f, 8.0f, 0.5f);
        HAL_Delay(5);
        
    }
    
		 
		 
}

// ================== 单腿 IK + 简单力控 (弹簧阻尼模型) ==================
/*void leg_set_position_idx(uint8_t leg_idx, float x, float y)
{
    // ---------- 1. IK 解算 (得到目标关节角度) ----------
    float cx = -x;
    float cy = y;
    if (leg_idx >= 2) cx = -cx;

    float L_sq = cx * cx + cy * cy;
    float L = sqrtf(L_sq);
    L = clamp_f(L, fabsf(L1 - L2_EFF) + 5.0f, (L1 + L2_EFF) * 0.95f);

    float psi = asinf(clamp_f(-cx / L, -1.0f, 1.0f));
    float phi = acosf(clamp_f((L_sq + L1 * L1 - L2_EFF * L2_EFF) / (2.0f * L1 * L), -1.0f, 1.0f));

    float theta1 = -(phi - psi);
    float theta2 = -(phi + psi);

    // 加上机械偏移，得到目标关节角度（弧度）
    float pos1_rad = theta1 + OFFSET_ANGLE;
    float pos2_rad = theta2 + OFFSET_ANGLE;

    // ---------- 2. 获取当前实际关节角度 (用于反馈) ----------
    float actual_rad1 = 0.0f;
    float actual_rad2 = 0.0f;

    if (leg_idx < 2) {
        // 从CAN1读取实际角度
        actual_rad1 = mi_motor_can1[leg_idx * 2].Angle;
        actual_rad2 = mi_motor_can1[leg_idx * 2 + 1].Angle;
    } else {
        uint8_t base = (leg_idx - 2) * 2;
        // 从CAN2读取实际角度
        actual_rad1 = mi_motor_can2[base].Angle;
        actual_rad2 = mi_motor_can2[base + 1].Angle;
    }

    // ---------- 3. 计算简单力控：弹簧阻尼力 ----------
    // 刚度系数 (Stiffness)：让机器人像个弹簧
    float k_spring = -0.2f;  // 值越大越硬，越小越软
    // 阻尼系数 (Damping)：吸收震动
    float d_damping = -1.0f;  // 值越大，运动越平稳，但反应越迟钝

    // 计算位置误差 (目标 - 实际)
    float error1 = pos1_rad - actual_rad1;
    float error2 = pos2_rad - actual_rad2;

    // 计算力矩前馈 (弹簧力 = k * error)
    float torque_feedforward1 = k_spring * error1;
    float torque_feedforward2 = k_spring * error2;

    // 注意：`motor_controlmode` 内部已经包含位置和速度的 PID 环。
    // 我们这里在 `torque` 参数里加一个弹簧力前馈，相当于给电机一个“预拉力”。
    // 这样机器人就会有弹性，不会僵死。

    // ---------- 4. 发送指令 ----------
    if (leg_idx < 2) {
       
        motor_controlmode(&mi_motor_can1[leg_idx * 2], torque_feedforward1, pos1_rad, 0.0f, 8.0f, 0.7f);
        motor_controlmode(&mi_motor_can1[leg_idx * 2 + 1], torque_feedforward2, pos2_rad, 0.0f, 8.0f, 0.7f);
    } else {
        uint8_t base = (leg_idx - 2) * 2;
  
        motor_controlmode(&mi_motor_can2[base], -torque_feedforward1, -pos1_rad, 0.0f, 8.0f, 0.7f);
        motor_controlmode(&mi_motor_can2[base + 1], -torque_feedforward2, -pos2_rad, 0.0f, 8.0f, 0.7f);
    }
}*/
void leg_set_position_idx(uint8_t leg_idx, float x, float y)
{
    // ---------- IK 解算（保持不变） ----------
    float cx = -x;
    float cy = y;
    if (leg_idx >= 2) cx = -cx;

    float L_sq = cx * cx + cy * cy;
    float L = sqrtf(L_sq);
    L = clamp_f(L, fabsf(L1 - L2_EFF) + 5.0f, (L1 + L2_EFF) * 0.95f);

    float psi = asinf(clamp_f(-cx / L, -1.0f, 1.0f));
    float phi = acosf(clamp_f((L_sq + L1 * L1 - L2_EFF * L2_EFF) / (2.0f * L1 * L), -1.0f, 1.0f));

    float theta1 = -(phi - psi);
    float theta2 = -(phi + psi);

    float pos1_rad = theta1 + OFFSET_ANGLE;
    float pos2_rad = theta2 + OFFSET_ANGLE;

    // ---------- 获取实际角度 ----------
    float actual_rad1 = 0.0f, actual_rad2 = 0.0f;
    float actual_vel1 = 0.0f, actual_vel2 = 0.0f;  // 需要获取实际速度，如果没有则用差分估算

    if (leg_idx < 2) {
        actual_rad1 = mi_motor_can1[leg_idx * 2].Angle;
        actual_rad2 = mi_motor_can1[leg_idx * 2 + 1].Angle;
        // 假设电机结构体中也有速度：.Speed
        actual_vel1 = mi_motor_can1[leg_idx * 2].Speed;
        actual_vel2 = mi_motor_can1[leg_idx * 2 + 1].Speed;
    } else {
        uint8_t base = (leg_idx - 2) * 2;
        actual_rad1 = mi_motor_can2[base].Angle;
        actual_rad2 = mi_motor_can2[base + 1].Angle;
        actual_vel1 = mi_motor_can2[base].Speed;
        actual_vel2 = mi_motor_can2[base + 1].Speed;
    }

    // ---------- 改进的力控：正刚度 + 阻尼 ----------
    // 刚度系数 (Stiffness)：根据当前腿的垂直高度 y 动态调整，使支撑力平稳
    // 基本刚度：当 y = 213.2mm 时，Kp_spring = 1.5 Nm/rad（经验值）
    float base_stiffness = 2.0f;
    // 高度补偿因子：y 越大（腿越长）刚度适当增大，防止“软”；y 越小（腿越短）刚度减小，防止“蹦”
    float height_factor = 213.2f / y;   // y 为当前目标高度，注意避免除零
    height_factor = clamp_f(height_factor, 0.8f, 1.5f);
    float stiffness = base_stiffness * height_factor;

    // 阻尼系数 (Damping)：抑制震荡，与速度成正比
    float damping = 0.1f;   // 0.05~0.15 可调

    float error1 = pos1_rad - actual_rad1;
    float error2 = pos2_rad - actual_rad2;

    // 弹簧力矩 = 刚度 * 误差
    float torque_spring1 = stiffness * error1;
    float torque_spring2 = stiffness * error2;

    // 阻尼力矩 = 阻尼系数 * (0 - 实际速度)  即抵抗运动
    float torque_damp1 = -damping * actual_vel1;
    float torque_damp2 = -damping * actual_vel2;

    // 总前馈力矩 = 弹簧力矩 + 阻尼力矩
    float torque_feedforward1 = torque_spring1 + torque_damp1;
    float torque_feedforward2 = torque_spring2 + torque_damp2;

    // 安全限幅（防止过大电流）
    const float MAX_TORQUE = 12.0f;   // 单位 Nm（根据电机实际能力调整）
    torque_feedforward1 = clamp_f(torque_feedforward1, -MAX_TORQUE, MAX_TORQUE);
    torque_feedforward2 = clamp_f(torque_feedforward2, -MAX_TORQUE, MAX_TORQUE);
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

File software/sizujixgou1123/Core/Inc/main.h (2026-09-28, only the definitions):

#define S2_Pin GPIO_PIN_5
#define S2_GPIO_Port GPIOE
#define S3_Pin GPIO_PIN_6
#define S3_GPIO_Port GPIOE
#define S1_Pin GPIO_PIN_1
#define S1_GPIO_Port GPIOF
#define LED8_Pin GPIO_PIN_8
#define LED8_GPIO_Port GPIOG
#define LED7_Pin GPIO_PIN_7
#define LED7_GPIO_Port GPIOG
#define LED6_Pin GPIO_PIN_6
#define LED6_GPIO_Port GPIOG
#define LED5_Pin GPIO_PIN_5
#define LED5_GPIO_Port GPIOG
#define LED4_Pin GPIO_PIN_4
#define LED4_GPIO_Port GPIOG
#define LED3_Pin GPIO_PIN_3
#define LED3_GPIO_Port GPIOG
#define LED2_Pin GPIO_PIN_2
#define LED2_GPIO_Port GPIOG
#define S4_Pin GPIO_PIN_2
#define S4_GPIO_Port GPIOC
#define S5_Pin GPIO_PIN_3
#define S5_GPIO_Port GPIOC
#define LED1_Pin GPIO_PIN_1
#define LED1_GPIO_Port GPIOG
#define S6_Pin GPIO_PIN_4
#define S6_GPIO_Port GPIOC
#define S7_Pin GPIO_PIN_5
#define S7_GPIO_Port GPIOC

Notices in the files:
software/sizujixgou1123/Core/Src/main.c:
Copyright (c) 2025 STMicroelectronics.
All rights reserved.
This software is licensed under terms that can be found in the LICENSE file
